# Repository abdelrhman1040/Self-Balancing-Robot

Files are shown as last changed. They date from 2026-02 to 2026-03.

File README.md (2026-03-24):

# Self-Balancing Robot
### Inverted Pendulum Modeling, Embedded Control, and Real-Time PID Tuning Platform

</div>

## Project Overview

This project implements a self-balancing robot based on the classical inverted pendulum problem. The system is inherently unstable and requires continuous feedback control to maintain its upright position.

Distinct from standard implementations, this robot features a **Web-based Dashboard** hosted directly on the ESP32. This allows for **real-time PID tuning** and telemetry visualization over Wi-Fi, eliminating the need to re-upload firmware for parameter adjustments.

### Key Features
* **Mathematical Modeling:** Linearization and transfer function derivation of the system.
* **Control System Design:** Implementation of cascaded PID loops for stability and drift control.
* **Embedded Firmware:** High-frequency control loop execution on the ESP32 dual-core architecture.
* **Web Interface:** Real-time tuning and data plotting using WebSockets.
* **Hardware Implementation:** Custom PCB design and 3D printed mechanical chassis.

### Applications
* Autonomous robotics platforms.
* Mobile balancing transport systems.
* Educational control systems laboratories.
* Real-time embedded control experimentation.

---

## Repository Contents

This repository is organized into the following directories:

* **[`/Firmware`](./Firmware)**: Source code (PlatformIO/Arduino) and libraries.
* **[`/PCB`](./PCB)**: EasyEDA Gerber files, schematics, and BOM.
* **[`/Mechanical`](./Mechanical)**: STL files for 3D printing and CAD models.
* **[`/Hardware`](./Hardware)**: Component datasheets, wiring diagrams, and hardware specifications.

---

## Hardware Assembly

### 1. Mechanical Assembly

1.  **Chassis Fabrication:** 3D print the chassis using the STL files provided in the `/Mechanical` directory.
2.  **Motor Mounting:** Mount the NEMA17 stepper motors in the designated chassis slots.
3.  **Drive Train:** Securely attach the wheels to the motor shafts.
4.  **Electronics Mounting:** Fix the PCB in its mounting slots using M3 screws.
5.  **IMU Alignment:** Place the BNO055 IMU sensor at the physical center of the robot.
    * *Note:* Misalignment introduces centrifugal acceleration artifacts into the tilt reading.
6.  **Center of Mass:** Ensure the center of mass is aligned vertically above the wheel axis.

### 2. Electrical Assembly

Connect the components according to the schematic provided in the `/PCB` directory:

* **Microcontroller:** ESP32 Development Board.
* **Actuators:** Two Stepper Motors driven by A4988 or DRV8825 drivers.
* **Sensor:** BNO055 IMU communicating via I2C (SDA, SCL).
* **Power Management:** Buck converter (16V to 5V) for logic supply; direct battery connection for motor drivers.

**Verification Steps:**
* Calibrate motor driver current limits (Vref).
* Verify common ground continuity between logic and power circuits.
* Ensure I2C connections are secure and shielded.

---

## Firmware Configuration and Upload

To configure and upload the firmware:

1.  Open the project in **PlatformIO** or **Arduino IDE**.
2.  Navigate to the main configuration file (e.g., `config.h` or `main.cpp`).
3.  Update the Wi-Fi credentials:

    ```cpp
    const char* ssid = "your_wifi_name";
    const char* password = "your_wifi_password";
    ```

4.  Upload the firmware to the ESP32.
5.  Open the Serial Monitor (Baud Rate: 115200).
6.  Upon successful connection, the ESP32 will output its assigned IP address.
7.  Enter this IP address in a web browser to access the control dashboard.

---

## Mathematical Modeling

The robot is modeled as an inverted pendulum mounted on a wheeled cart.

```math
(M + m)\ddot{x} + mL \cos\theta \ddot{\theta}
- mL\dot{\theta}^2 \sin\theta = F(x)
```
### 2. Pendulum Rotation

```math
mL \cos\theta \ddot{x}
+ (I + mL^2)\ddot{\theta}
- mgL\sin\theta = d(\theta)
```

These equations contain nonlinear terms:
$\sin\theta$, $\cos\theta$, $\dot{\theta}^2$

For small angles:

$$
\sin\theta \approx \theta
$$

$$
\cos\theta \approx 1
$$

The simplified equation becomes:

$$
(I + mL^2)\ddot{\theta} - mgL\theta = d(\theta)
$$

### Transfer Function

$$
\frac{\Theta(s)}{D(s)} = \frac{1}{s^2 - a}
$$

Where

$$
a = \frac{mgL}{I + mL^2}
$$

Poles:

$$
s = \pm \sqrt{a}
$$

### Embedded Control Architecture

The firmware utilizes a **Cascaded Control Architecture**:

1.  **Balance Loop (Inner Loop):**
    * Operates at high frequency (~200Hz).
    * Calculates motor speed based on tilt angle.
    * Includes anti-windup and deadband compensation.

    ```cpp
    float term_bP = Kp * balanceError;
    float term_bI = Ki * sumBalanceError;
    float term_bD = Kd * (balanceError - lastBalanceError);
    ```

2.  **Speed/Drift Loop (Outer Loop):**
    * Operates at a lower frequency.
    * Adjusts the target angle setpoint to prevent linear drift across the floor.

    ```cpp
    float term_sP = speedOutput * Kp_s;
    float term_sI = sumSpeedError * Ki_s;
    float driftCorrection = term_sP + term_sI;
    ```

---

## Web Dashboard Interface

The ESP32 hosts an asynchronous web server providing a control interface with the following functionalities:

* **Parameter Tuning:** Sliders for adjusting $K_p$, $K_i$, and $K_d$ values for both balance and speed loops instantly.
* **Telemetry:** Live plotting of tilt angle, motor speed, and PID output using Chart.js.
* **Control:** Remote start/stop functionality.
* **Data Persistence:** Capability to save and load tuning profiles from non-volatile memory (EEPROM).



<div align="center">

<a href="https://www.youtube.com/shorts/-zBhrWm9mPE" target="_blank">
   Watch Video
</a>

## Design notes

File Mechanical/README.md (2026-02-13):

# Mechanical Specifications

* **Material:** PLA+ 

| Component | Infill Percentage | Infill Pattern |
| :--- | :---: | :---: |
| **Wheels** | **50%** | Gyroid / Grid | 
| **Main Body** | **30%** | Tri-Hexagonal | 



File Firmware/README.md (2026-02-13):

# Firmware Documentation

## Overview
The firmware is built on the Arduino Framework specifically for the ESP32 Dual-Core architecture. It is designed to decouple critical real-time control loops from non-deterministic Wi-Fi and Web Server tasks. This separation ensures that heavy network traffic or web dashboard updates do not interrupt the PID loop, maintaining consistent stability for the robot.

---

## System Architecture

The firmware utilizes FreeRTOS to distribute tasks across the two cores of the ESP32:

### 1. Core 1: Real-Time Control Task (High Priority)
This core is dedicated to the physics and stability of the robot.
* Frequency: ~100Hz (10ms loop time).
* Responsibilities:
    * Sensor Fusion: Reads absolute orientation data from the BNO055 IMU via I2C.
    * PID Calculation: Computes the Cascaded PID output (Balance Inner Loop + Speed Outer Loop).
    * Motor Drive: Generates step pulses using the AccelStepper library with acceleration limiting.
    * Safety Checks: Monitors tilt angle (automatic cutoff at >45 degrees) and sensor connectivity.

### 2. Core 0: Communication Task (Low Priority)
This core handles user interaction and network management.
* Responsibilities:
    * Wi-Fi Management: Handles connection stability and re-connection logic.
    * Web Server: Serves the HTML/JavaScript Dashboard to the browser.
    * API Handling: Processes AJAX requests for real-time tuning and telemetry data.
    * NVS Storage: Manages reading/writing tuning profiles to Flash memory via the Preferences library.

---

## Dependencies and Libraries

The following libraries are required to compile the project:

| Library | Purpose |
| :--- | :--- |
| Adafruit BNO055 | Driver for the IMU sensor to read Euler angles. |
| Adafruit Unified Sensor | Base dependency for Adafruit sensor libraries. |
| AccelStepper | Multi-stepper control with acceleration support. |
| Preferences | Non-Volatile Storage (NVS) management on ESP32. |
| WebServer | Standard library for handling HTTP requests. |

---

## Pin Definitions and Hardware Compatibility

The firmware defaults to the configuration for PCB Version 1 (V1).

### Current Pinout (V1 Default)
```cpp
#define STEP_PIN_1   14   // Left Motor Step
#define DIR_PIN_1    12   // Left Motor Dir
#define STEP_PIN_2   26   // Right Motor Step
#define DIR_PIN_2    27   // Right Motor Dir
#define SDA_PIN      21   // BNO055 SDA
#define SCL_PIN      22   // BNO055 SCL
```

---

## Important for PCB V2 Users
The PCB Version 2 design avoids using GPIO 2 to prevent boot-strapping issues. If you are deploying this firmware on a V2 board, you must update the pin definitions in the source code to match the V2 schematic before uploading. Failure to do so may result in boot loops or unresponsive motors.

---

## Troubleshooting and System Stability

### Brownout Detector Issue (PCB V1)
In the initial PCB design (V1), the power path is shared between high-current stepper drivers and the ESP32 logic without complete electrical isolation.

**The Problem:**
Rapid motor acceleration causes significant current spikes, leading to a momentary voltage drop on the 3.3V rail. The ESP32's internal Brownout Detector interprets this as a power failure and resets the chip, causing a continuous boot loop during operation.

**The Software Solution:**
If your robot resets whenever it tries to balance or move (especially on PCB V1), the code includes a fix to disable the Brownout Detector at the start of the setup function:

```cpp
#include "soc/soc.h"
#include "soc/rtc_cntl_reg.h"

void setup() {
    // Disabling Brownout Detector to allow operation during current spikes
    WRITE_PERI_REG(RTC_CNTL_BROWN_OUT_REG, 0);
    
    // ... remaining setup logic
}
```

> **Note:** While this software fix allows the robot to run, ensure your 3S LiPo battery is adequately charged to maintain voltage stability.

---

## API Endpoints (Web Interface)
The Web Dashboard interacts with the ESP32 through HTTP GET requests.

| Endpoint | Description |
| :--- | :--- |
| **`GET /data`** | Returns a JSON object with live telemetry (Angle, Speed, PID components). |
| **`GET /set?k=[KEY]&v=[VALUE]`** | Updates PID constants instantly.<br>**Keys:** `bp` (Balance P), `bi` (Balance I), `bd` (Balance D), `sp` (Setpoint). |
| **`GET /save?p=[SLOT]`** | Saves current tuning to Slot 1, 2, or 3 in Flash memory. |
| **`GET /move?d=[DIRECTION]`** | Sends movement commands.<br>**Values:** `F` (Forward), `B` (Backward), `L` (Left), `R` (Right). |

WhatsApp Image 2026-02-13 at 10 07 07 PM



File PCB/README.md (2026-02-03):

## PCB Versions

### Version 1 (V1) - Prototype
This version represents the initial design of the board, characterized by the following specifications and limitations:

* **Microcontroller:** The board only supports the 38-pin ESP32 module.
* **Power:** The power path is shared between the step-down converter and the ESP32 without isolation, preventing USB connection while running on an external battery.
* **Drivers Logic:** Operates at a fixed 3.3V logic voltage (may not be compatible with some clone A4988 drivers that require 5V, unless tracks are manually modified).
* **Control:** Microstepping and Enable settings are hardwired (manually set) and cannot be controlled via code.
* **Installation Notes:**
    * Installing headers requires connecting only the used pins to avoid restart loop issues.
    * The sensor port footprint is reversed by 180 degrees.

---

### Version 2 (V2) - Improved Version
This version was developed to include comprehensive improvements in power management, compatibility, and pin selection:

* **Controller Support:** The board supports mounting ESP32 modules of two different sizes: **30-pin** and **38-pin**.
* **Power Management:**
    * **Isolation Switch:** Allows disconnecting the step-down output from the ESP32, enabling safe chip programming via USB without disconnecting the external power source.
    * **Logic Voltage Selection:** A switch to select the drivers' logic voltage between **3.3V** and **5V** to ensure compatibility with all driver types.
* **Software Control:** Control pins (MS1, MS2, MS3) and the Enable pin are connected to the microcontroller (GPIO) to allow full software control.
* **Pin Selection Optimization:** Avoided using **GPIO 2** for driver control to prevent booting issues occasionally caused by this pin.
* **Extras:**
    * **Voltage Sensor:** Integrated circuit to read input voltage (up to **17V** max).
    * **Track Correction:** The sensor ports' orientation has been corrected to the standard position.

---

### ⚠️ Important Notes
* This design (V2) is still experimental and has not been practically tested yet (Untested).

* Due to the change in the Pinout for this version (specifically avoiding GPIO 2), the Pin Definitions in the software code must be updated to match the new connections before operation.

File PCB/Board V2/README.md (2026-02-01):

# PCB V2




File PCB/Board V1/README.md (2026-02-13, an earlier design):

# PCB V1




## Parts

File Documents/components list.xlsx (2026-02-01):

Name | quantity | connection protocol | datasheet
ESP32 DIP-38 | 1 | ___ | https://documentation.espressif.com/esp32_datasheet_en.pdf
42BYGH37 | 2 | GPIO | https://joy-it.net/files/files/Produkte/NEMA17-06/NEMA17-06_Datasheet.pdf
MAX7219 8X8 | 2 | SPI | MAX7219/MAX7221 - Serially Interfaced, 8-Digit LED Display Drivers (https://www.analog.com/media/en/technical-documentation/data-sheets/max7219-max7221.PDF)
GY-BNO055 | 1 | I2C | https://cdn-shop.adafruit.com/datasheets/BST_BNO055_DS000_12.pdf
PCB | 1 | ___ | ___
18650 Battery Holder – 2 Cells | 2 | ___ | ___
8650 Li-ion Battery Samsung | 4 | ___ | ___
LM2596 DC-DC Buck Converter Step-Down | 1 | ___ | https://www.ti.com/lit/ds/symlink/lm2596.pdf
A4988 Stepper Motor Driver | 2 | GPIO | https://www.pololu.com/file/0j450/a4988_dmos_microstepping_driver_with_translator.pdf
Electrolytic Capacitor 100uF – 50v | 2 | ___ | ___
Pin Header Female | 2 | ___ | ___
Pin Header Male | 2 | ___ | ___

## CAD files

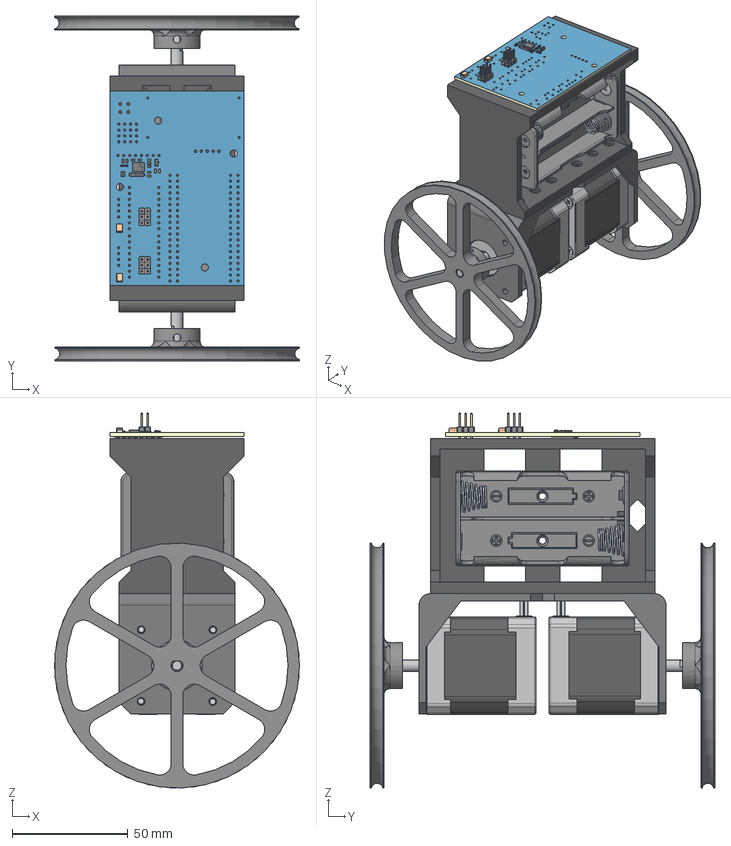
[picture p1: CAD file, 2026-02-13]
Mechanical/Self Balancing Robot.step
106.0 x 149.0 x 162.2 mm
NEMA_17_Bracket x 2
17HM19-2004S x 2
Wheel v2 x 2
spring x 4
2_rivets_1 x 2
2_rivets_2 x 2
positif x 4
Board~hV0o
HDR-TH_3P-P2.54-V-M-1~HDR-M-2.54_1x3~hV0o x 4
ELECTROLYTIC_CAPACITOR_5X11~CAP-SMD_L3.5-W2.8-FD~hV0o x 2
BNO055~GY-BNO055~hV0o
BNO055~GY-BNO055~hV0o_1
BNO055~GY-BNO055~hV0o_2
BNO055~GY-BNO055~hV0o_3
BNO055~GY-BNO055~hV0o_4
BNO055~GY-BNO055~hV0o_5
BNO055~GY-BNO055~hV0o_6
BNO055~GY-BNO055~hV0o_7
BNO055~GY-BNO055~hV0o_8
BNO055~GY-BNO055~hV0o_9
BNO055~GY-BNO055~hV0o_10
BNO055~GY-BNO055~hV0o_11
BNO055~GY-BNO055~hV0o_12
BNO055~GY-BNO055~hV0o_13
BNO055~GY-BNO055~hV0o_14
BNO055~GY-BNO055~hV0o_15
BNO055~GY-BNO055~hV0o_16
BNO055~GY-BNO055~hV0o_17
BNO055~GY-BNO055~hV0o_18
BNO055~GY-BNO055~hV0o_19

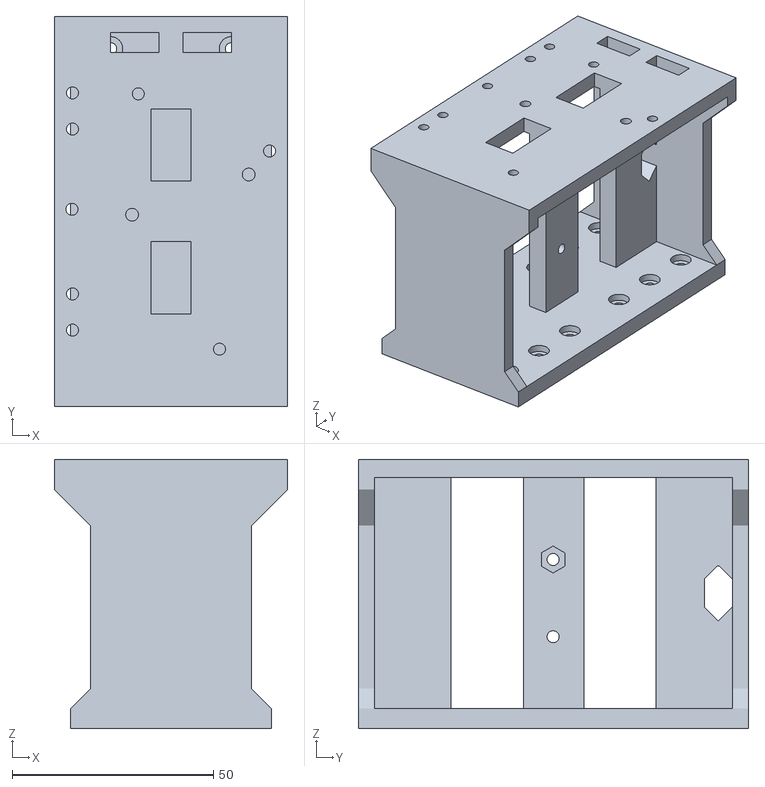
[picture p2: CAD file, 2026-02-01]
Mechanical/body.stl
58.0 x 97.0 x 67.0

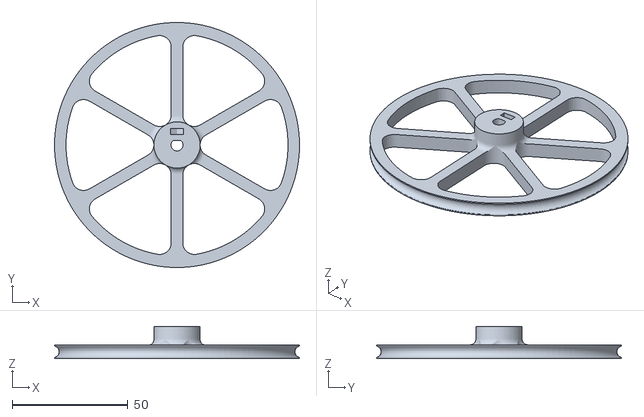
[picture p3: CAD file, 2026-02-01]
Mechanical/Wheel 6.stl
106.0 x 106.0 x 14.0

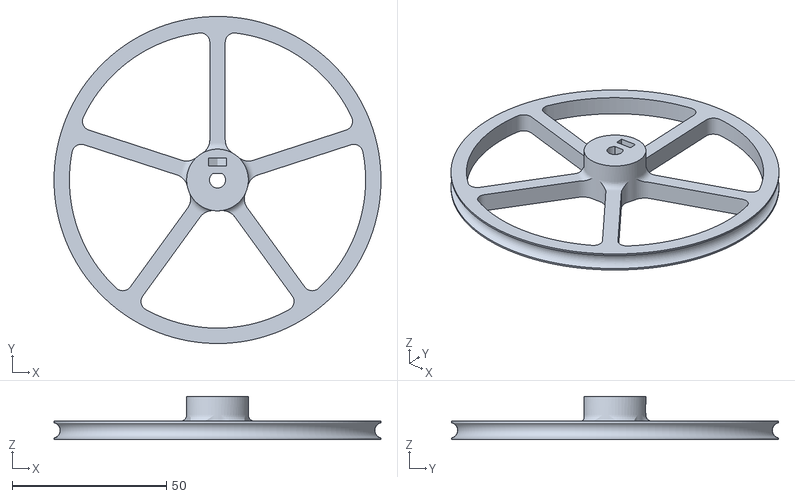
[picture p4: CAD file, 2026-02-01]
Mechanical/Wheel 5.stl
106.0 x 106.0 x 14.0

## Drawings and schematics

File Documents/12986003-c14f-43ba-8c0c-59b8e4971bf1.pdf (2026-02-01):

ESP32 | GPIO

# A4988 Stepper 1

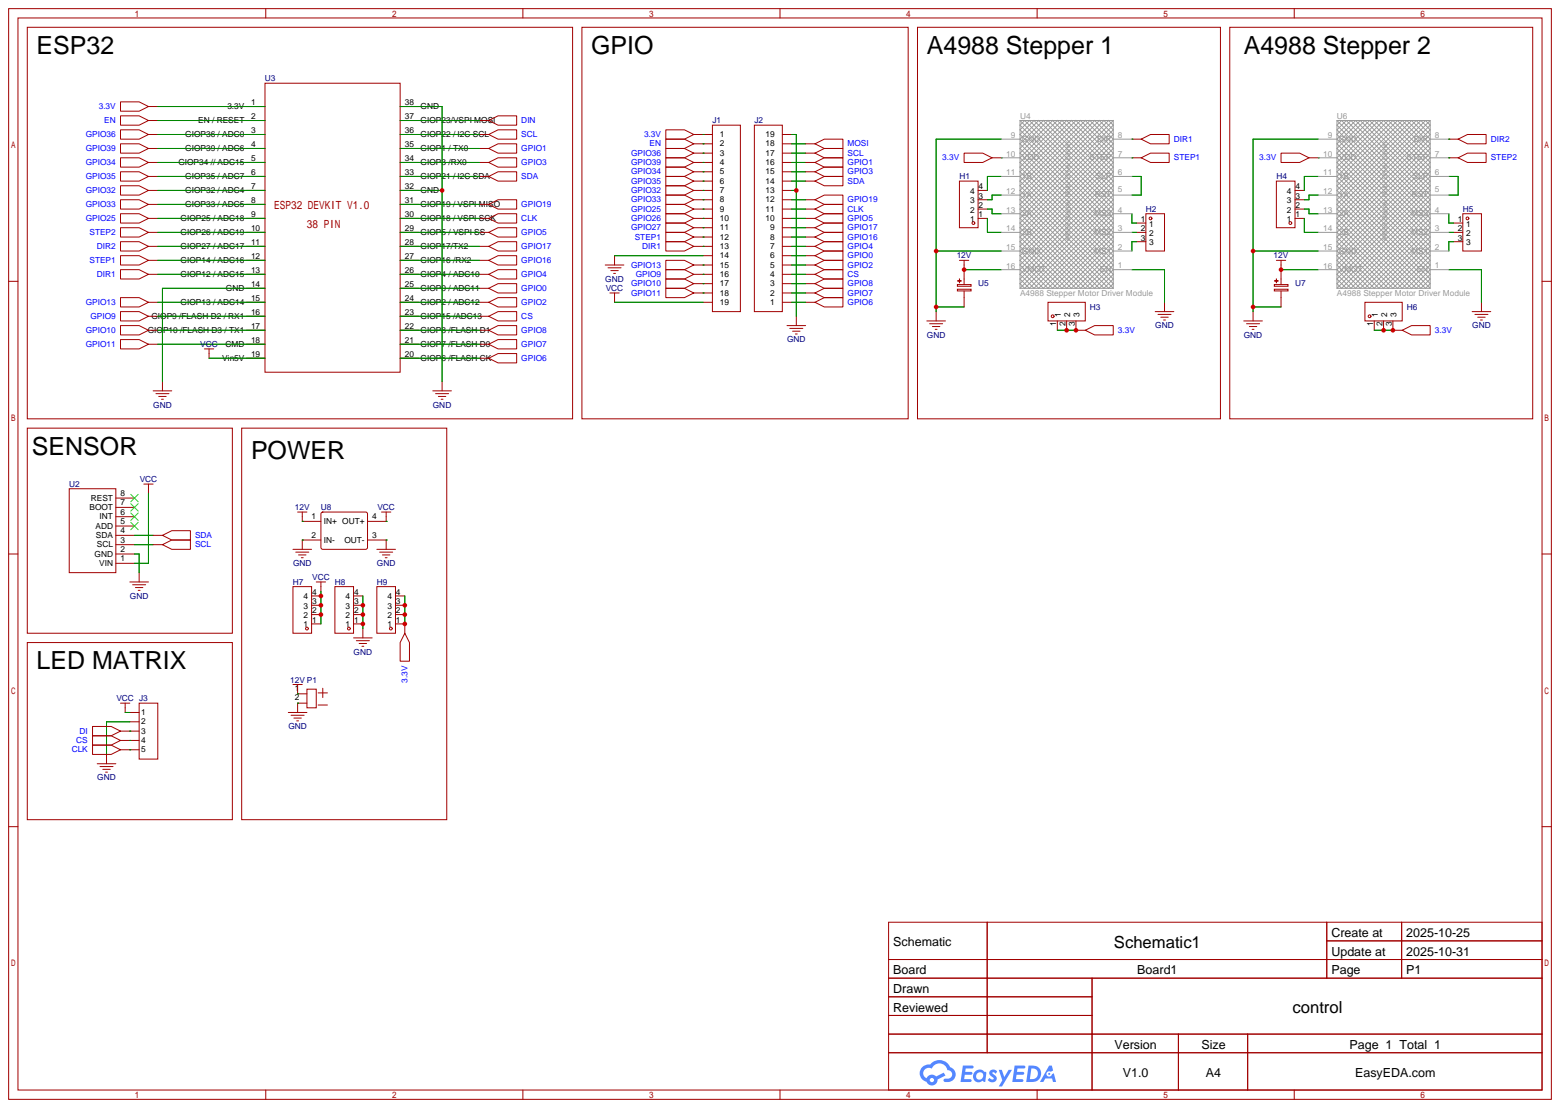
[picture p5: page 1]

A4988 Stepper Motor Driver Carrier

A4988 Stepper Motor Driver Module

Schematic | Schematic1 | Create at | 2025-10-25

Update at | 2025-10-31

Board | Board1 | Page | P1
Drawn | | control
Reviewed

Version | Size | Page 1 Total 1
V1.0 | A4 | EasyEDA.com

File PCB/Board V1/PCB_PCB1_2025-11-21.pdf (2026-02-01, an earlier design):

P1
IN+

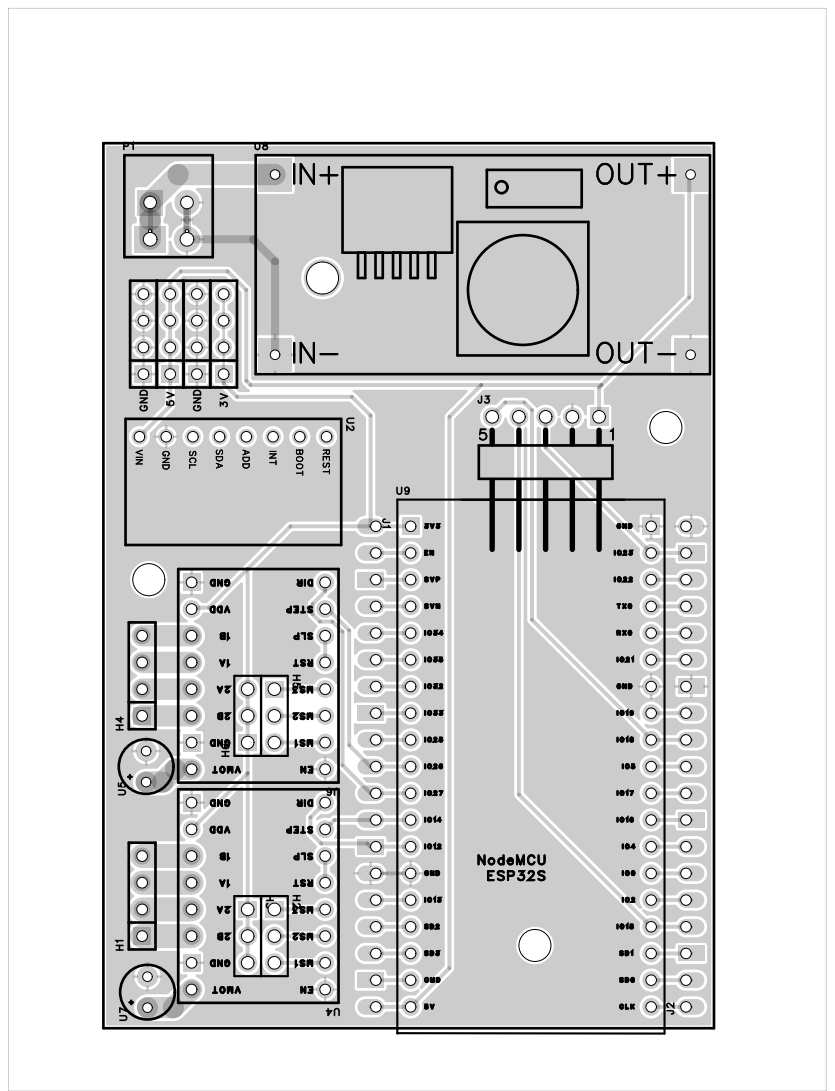
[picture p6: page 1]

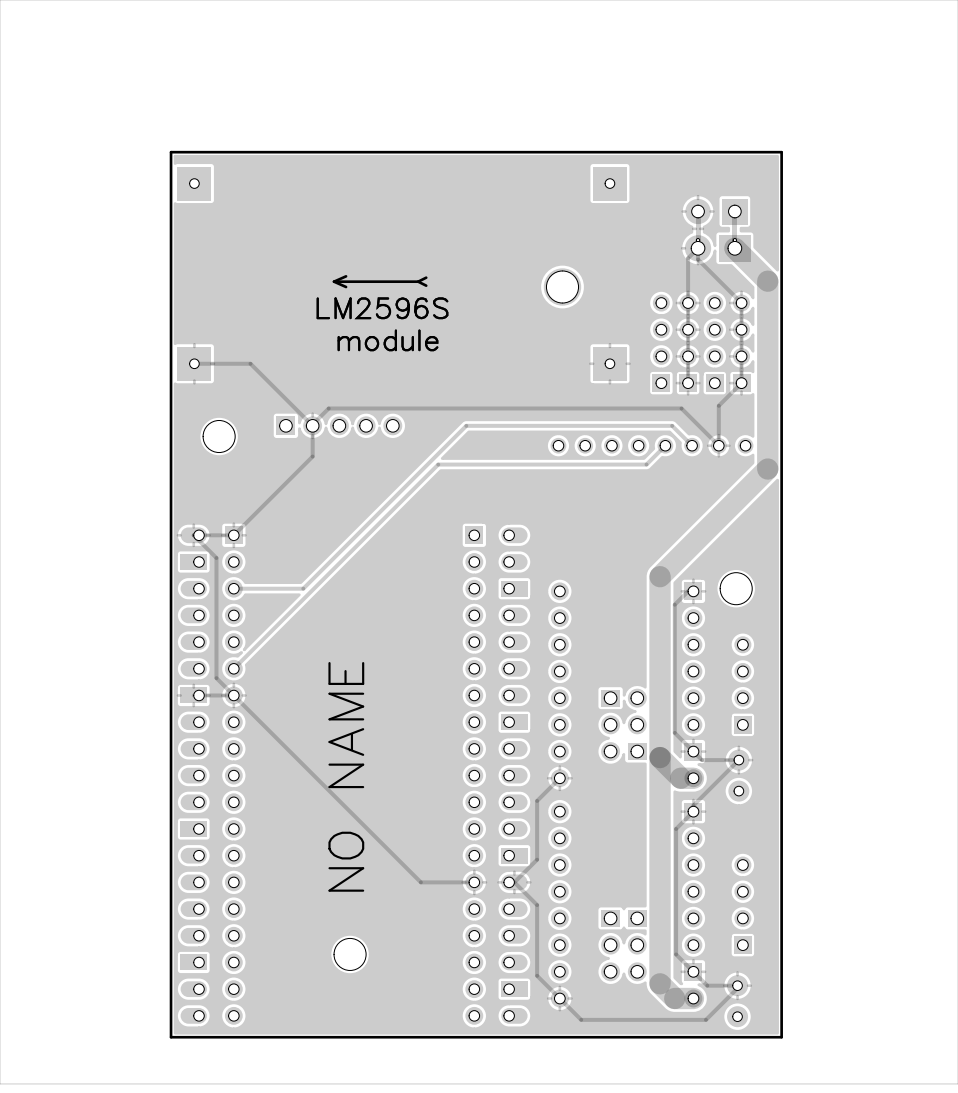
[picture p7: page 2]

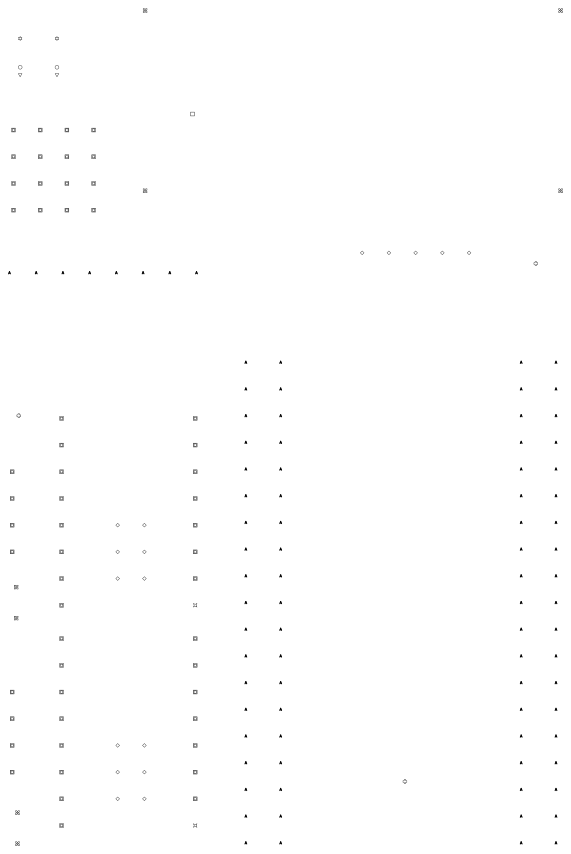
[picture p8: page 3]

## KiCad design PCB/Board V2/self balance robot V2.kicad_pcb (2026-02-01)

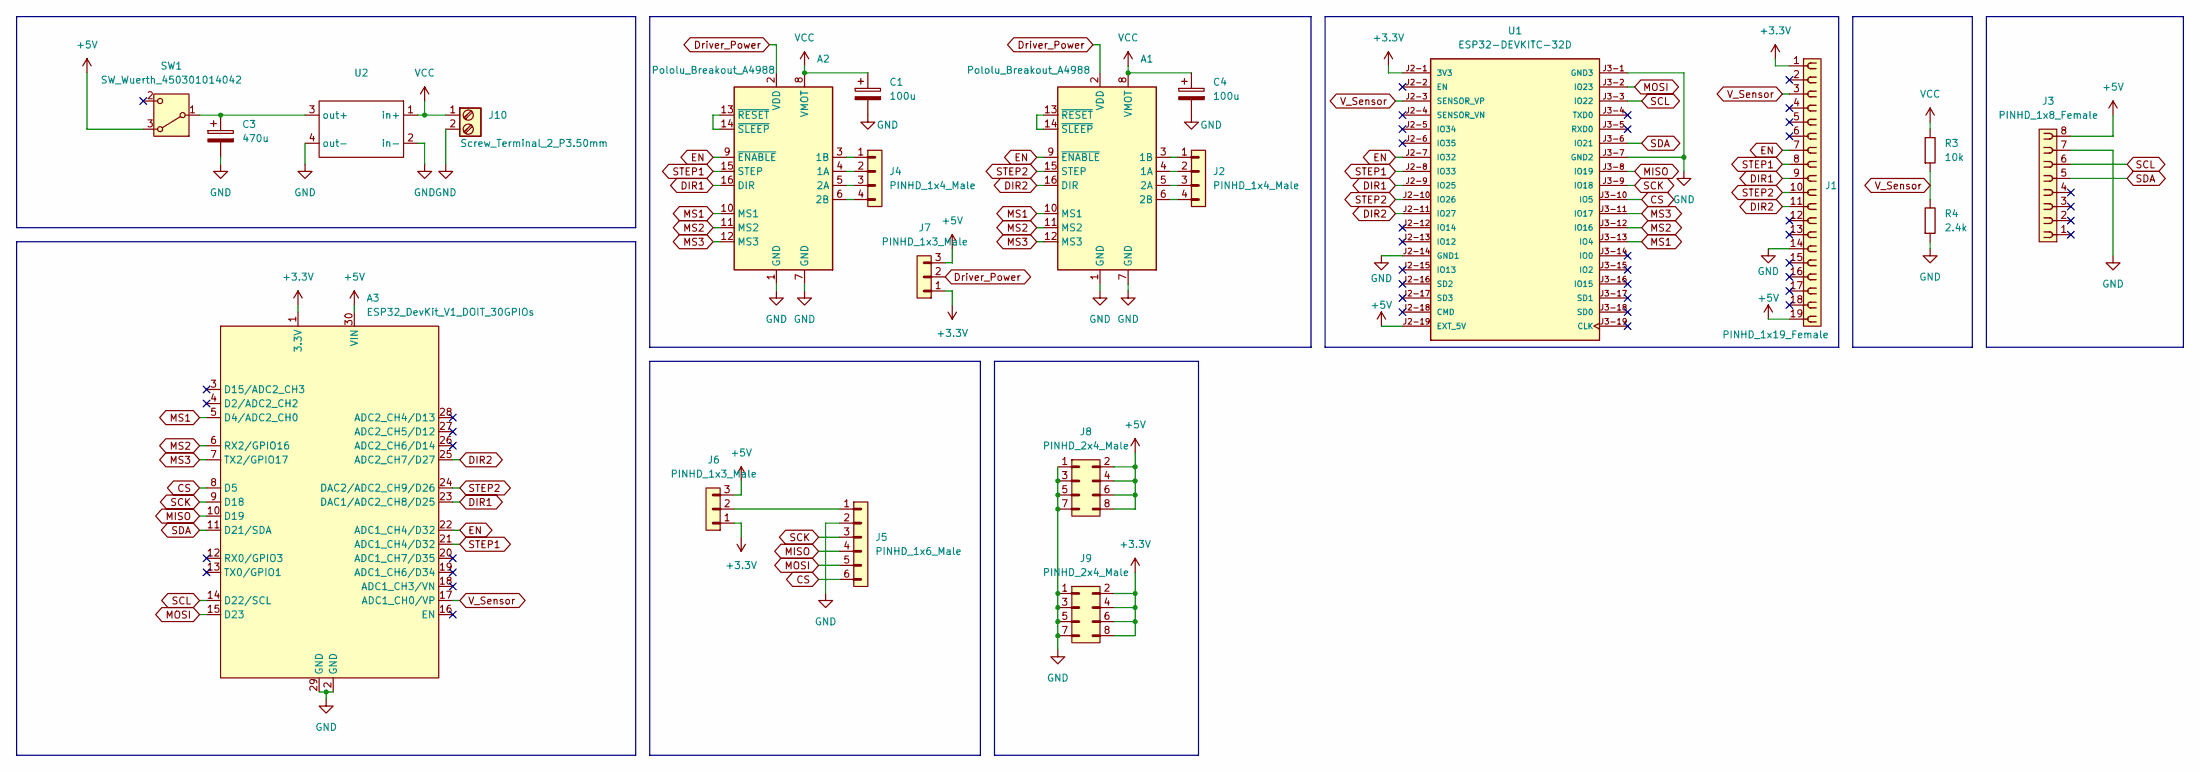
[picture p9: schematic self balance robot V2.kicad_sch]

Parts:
A1, A2: Pololu_Breakout_A4988; Pololu_Breakout-16_15.2x20.3mm
A3: ESP32_DevKit_V1_DOIT_30GPIOs; DOIT_ESP32_DEVKIT_30Pins
C1, C4: 100u; CP_Radial_D5.0mm_P2.50mm
C3: 470u; CP_Radial_D5.0mm_P2.50mm
J1: PINHD_1x19_Female; PinSocket_1x19_P2.54mm_Vertical
J2, J4: PINHD_1x4_Male; PinHeader_1x04_P2.54mm_Vertical
J3: PINHD_1x8_Female; PinSocket_1x08_P2.54mm_Vertical
J5: PINHD_1x6_Male; PinHeader_1x06_P2.54mm_Vertical
J6, J7: PINHD_1x3_Male; PinHeader_1x03_P2.54mm_Vertical
J8, J9: PINHD_2x4_Male; PinHeader_2x04_P2.54mm_Vertical
J10: Screw_Terminal_2_P3.50mm; TerminalBlock_Phoenix_PT-1,5-2-3.5-H_1x02_P3.50mm_Horizontal
R3: 10k; R_Axial_DIN0207_L6.3mm_D2.5mm_P10.16mm_Horizontal
R4: 2.4k; R_Axial_DIN0207_L6.3mm_D2.5mm_P10.16mm_Horizontal
SW1: SW_Wuerth_450301014042; SW_Slide-03_Wuerth-WS-SLTV_10x2.5x6.4_P2.54mm
U1: ESP32-DEVKITC-32D; MODULE_ESP32-DEVKITC-32D; PARTREV V4
U2: mini360

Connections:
+3.3V: A3.1 (3.3V), J1.1, J6.1, J7.1, J9.2, J9.4, J9.6, J9.8, U1.J2-1 (3V3)
+5V: A3.30 (VIN), J1.19, J3.8, J6.3, J7.3, J8.2, J8.4, J8.6, J8.8, SW1.3 (A), U1.J2-19 (EXT_5V)
CS: A3.8 (D5), J5.6, U1.J3-10 (IO5)
DIR1: A2.16 (DIR), A3.23 (DAC1/ADC2_CH8/D25), J1.9, U1.J2-9 (IO25)
DIR2: A1.16 (DIR), A3.25 (ADC2_CH7/D27), J1.11, U1.J2-11 (IO27)
Driver_Power: A1.2 (VDD), A2.2 (VDD), J7.2
EN: A1.9 (~ENABLE), A2.9 (~ENABLE), A3.22 (ADC1_CH4/D32), J1.7, U1.J2-7 (IO32)
GND: A1.1 (GND), A1.7 (GND), A2.1 (GND), A2.7 (GND), A3.2 (GND), A3.29 (GND), C1.2, C3.2, C4.2, J1.14, J3.7, J5.2, J8.1, J8.3, J8.5, J8.7, J9.1, J9.3, J9.5, J9.7, J10.2, R4.1, U1.J2-14 (GND1), U1.J3-1 (GND3), U1.J3-7 (GND2), U2.2 (in-), U2.4 (out-)
MISO: A3.10 (D19), J5.4, U1.J3-8 (IO19)
MOSI: A3.15 (D23), J5.5, U1.J3-2 (IO23)
MS1: A1.10 (MS1), A2.10 (MS1), A3.5 (D4/ADC2_CH0), U1.J3-13 (IO4)
MS2: A1.11 (MS2), A2.11 (MS2), A3.6 (RX2/GPIO16), U1.J3-12 (IO16)
MS3: A1.12 (MS3), A2.12 (MS3), A3.7 (TX2/GPIO17), U1.J3-11 (IO17)
unnamed: A1.4 (1A), J2.2
unnamed: A1.3 (1B), J2.1
unnamed: A1.5 (2A), J2.3
unnamed: A1.6 (2B), J2.4
unnamed: A1.13 (~RESET), A1.14 (~SLEEP)
unnamed: A2.4 (1A), J4.2
unnamed: A2.3 (1B), J4.1
unnamed: A2.5 (2A), J4.3
unnamed: A2.6 (2B), J4.4
unnamed: A2.13 (~RESET), A2.14 (~SLEEP)
unnamed: J5.1, J6.2
unnamed: C3.1, SW1.1 (B), U2.3 (out+)
SCK: A3.9 (D18), J5.3, U1.J3-9 (IO18)
SCL: A3.14 (D22/SCL), J3.6, U1.J3-3 (IO22)
SDA: A3.11 (D21/SDA), J3.5, U1.J3-6 (IO21)
STEP1: A2.15 (STEP), A3.21 (ADC1_CH4/D32), J1.8, U1.J2-8 (IO33)
STEP2: A1.15 (STEP), A3.24 (DAC2/ADC2_CH9/D26), J1.10, U1.J2-10 (IO26)
VCC: A1.8 (VMOT), A2.8 (VMOT), C1.1, C4.1, J10.1, R3.2, U2.1 (in+)
V_Sensor: A3.17 (ADC1_CH0/VP), J1.3, R3.1, R4.2, U1.J2-3 (SENSOR_VP)

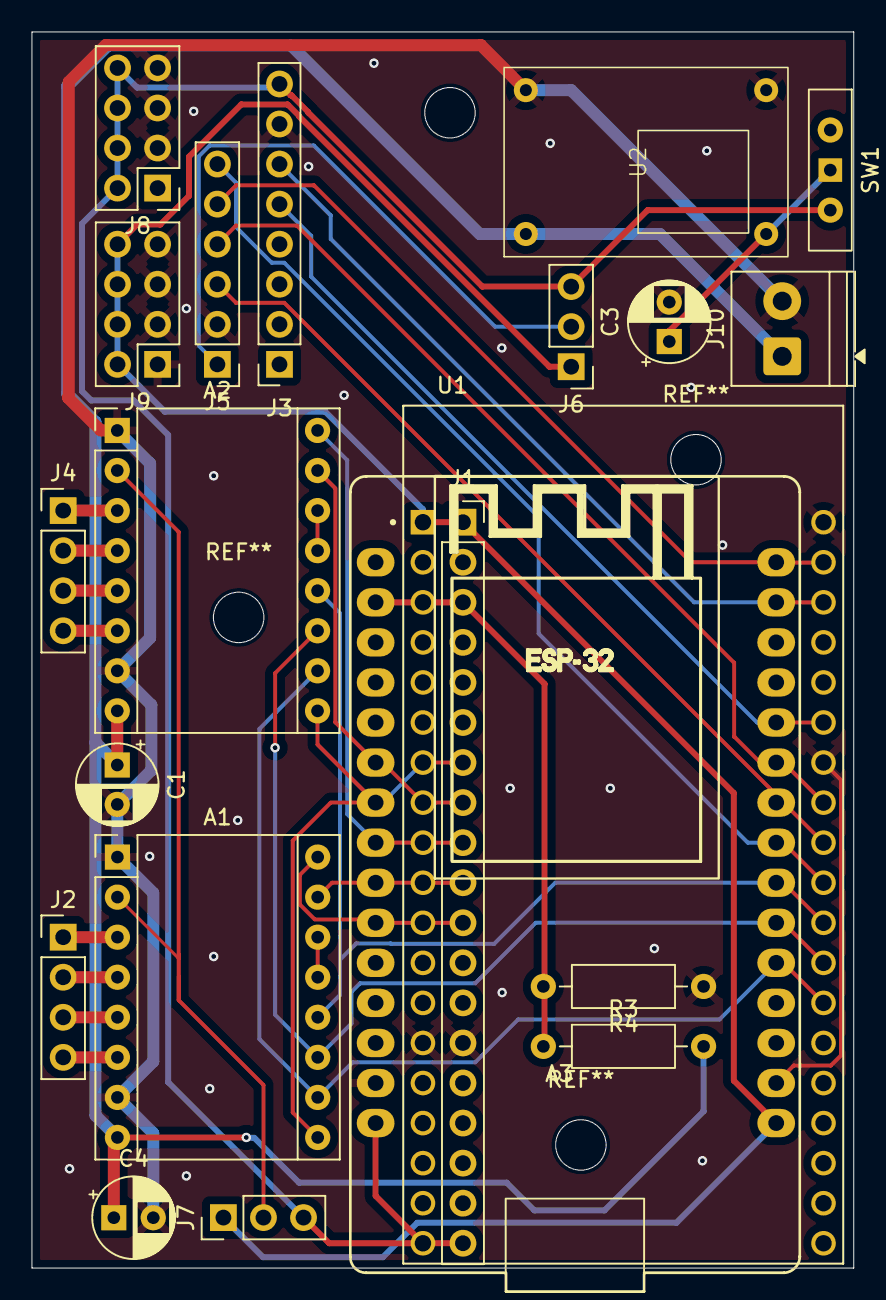
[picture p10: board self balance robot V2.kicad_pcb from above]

Board: 2 copper layers, 52.1 x 78.4 mm, 21 parts (0 on the bottom side), 32 nets.

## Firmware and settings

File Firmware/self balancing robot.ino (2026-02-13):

#include <Wire.h>
#include <Adafruit_Sensor.h>
#include <Adafruit_BNO055.h>
#include <AccelStepper.h>
#include <Preferences.h>
#include <WiFi.h>
#include <WebServer.h>
#include "soc/soc.h"
#include "soc/rtc_cntl_reg.h"

// --- Network Settings ---
const char* ssid = "your_wifi_name";
const char* password = "your_wifi_password";

// --- System Objects ---
Preferences preferences;
WebServer server(80);
Adafruit_BNO055 bno = Adafruit_BNO055(55, 0x29); 

// --- Pin Definitions ---
#define STEP_PIN_1   14   
#define DIR_PIN_1    12    
#define STEP_PIN_2   26   
#define DIR_PIN_2    27   

AccelStepper stepper1(AccelStepper::DRIVER, STEP_PIN_1, DIR_PIN_1);
AccelStepper stepper2(AccelStepper::DRIVER, STEP_PIN_2, DIR_PIN_2);

// --- PID Control Variables ---
volatile float Kp = 383, Ki = 5.3, Kd = 198.5;
volatile float setPoint = -1.4;
float deadband = 0.5;

// --- Drift Control ---
volatile float Kp_s = 0.0008; 
volatile float Ki_s = 0.0001; 

// --- Profile Management ---
int activeProfile = 1;

// --- Movement Variables ---
volatile float moveTilt = 0;   
volatile float turnSpeed = 0;  

// --- Variables ---
volatile float displayAngle = 0;
float speedOutput = 0, sumSpeedError = 0;
float lastBalanceError = 0, sumBalanceError = 0;
float desiredAngle = 0;

// --- DEBUG / GRAPH VARIABLES ---
volatile float dbg_bP = 0, dbg_bI = 0, dbg_bD = 0;
volatile float dbg_sP = 0, dbg_sI = 0;

const float FALL_LIMIT = 45.0; 
const float MAX_HW_SPEED = 12000; 
const float MAX_TILT = 5.0; 
bool sensorConnected = false;

TaskHandle_t Task1; 

// --- Web Dashboard ---
const char index_html[] PROGMEM = R"rawliteral(
<!DOCTYPE HTML><html>
<head>
   <meta name="viewport" content="width=device-width, initial-scale=1">
   <title>self balancing robot </title>
   <style>
      body { font-family: 'Segoe UI', sans-serif; background: #000; color: #eee; margin:0; padding:5px; text-align:center; }
      h2 { color: #f39c12; margin: 5px 0; font-size: 18px; }
      
      .container { display: flex; flex-wrap: wrap; justify-content: center; gap: 10px; }
      .card { background: #1e1e1e; padding: 10px; border-radius: 8px; box-shadow: 0 4px 10px rgba(0,0,0,0.5); width: 100%; max-width: 450px; }
      
      .live-vals { display: flex; justify-content: space-around; margin-bottom: 5px; }
      .live-num { font-size: 20px; font-weight: bold; color: #00bcd4; }
      .live-lbl { font-size: 10px; color: #aaa; }
      .lat-num { font-size: 18px; font-weight: bold; color: #e91e63; }

      /* ROBOT VISUALIZER STYLING */
      .vis-container { position: relative; width: 100%; height: 250px; background: #000; border-radius: 10px; border: 1px solid #333; margin-bottom: 10px; overflow: hidden; }
      canvas#cvsRobot { width: 100%; height: 100%; }

      /* Profile Styling */
      .prof-section { background: #222; padding: 10px; border-radius: 5px; margin-bottom: 5px; border: 1px solid #444; }
      .prof-row { display: flex; gap: 5px; margin-bottom: 5px; justify-content: center; }
      .p-btn { flex: 1; padding: 8px; background: #333; border: 1px solid #555; color: #fff; cursor: pointer; border-radius: 4px; font-size: 14px; }
      .p-active { background: #00bcd4; color: #000; font-weight: bold; border-color: #eee; }
      
      .action-btn { width: 48%; padding: 10px; font-weight: bold; cursor: pointer; border: none; border-radius: 5px; color: white; }
      .btn-save { background: #4CAF50; } 
      .btn-load { background: #FF9800; } 
      .btn-save:active, .btn-load:active { transform: scale(0.98); opacity: 0.8; }

      .graph-card { background: #000; border: 1px solid #333; border-radius: 8px; padding: 5px; width: 100%; max-width: 600px; }
      canvas#cvsMaster { width: 100%; height: 300px; display: block; }
      
      .legend { font-size: 11px; margin-top: 5px; display: flex; flex-wrap: wrap; justify-content: center; gap: 8px; }
      .legend label { cursor: pointer; display: flex; align-items: center; gap: 3px; user-select: none; }
      input[type=checkbox] { accent-color: #555; width: 15px; height: 15px; cursor: pointer; }

      input[type=range] { width: 100%; cursor: pointer; margin: 8px 0; }
      .row { display: flex; justify-content: space-between; font-size: 13px; color: #ccc; }
      .btn { background: #2196F3; border: none; color: white; padding: 5px; width: 50px; height: 50px; font-size: 20px; border-radius: 50%; margin: 3px; cursor: pointer; }
      .btn-stop { background: #f44336; width: 70px; height: 70px; border-radius: 15px; }
   </style>
</head>
<body>

   <h2>ESP32 Robot Visualizer</h2>

   <div class="container">
      <div class="card">
          
          <div class="vis-container">
              <canvas id="cvsRobot"></canvas>
          </div>

          <div class="prof-section">
             <div class="prof-row">
                <button id="p1" class="p-btn p-active" onclick="selProf(1)">P1</button>
                <button id="p2" class="p-btn" onclick="selProf(2)">P2</button>
                <button id="p3" class="p-btn" onclick="selProf(3)">P3</button>
             </div>
             <div class="prof-row">
                <button class="action-btn btn-save" onclick="doSave()">SAVE</button>
                <button class="action-btn btn-load" onclick="doLoad()">LOAD</button>
             </div>
          </div>

          <div class="live-vals">
             <div><span id="txtAng" class="live-num">0.0</span><br><span class="live-lbl">Angle</span></div>
             <div><span id="txtSpd" class="live-num">0.00</span><br><span class="live-lbl">m/s</span></div>
             <div><span id="txtLat" class="lat-num">0 ms</span><br><span class="live-lbl">Ping</span></div>
          </div>
      </div>
   </div>

   <div class="container" style="margin-top: 15px;">
      <div class="card">
         <h3>Balance PID</h3>
         <div class="row"><span>Kp</span><span id="v_kp">%KP%</span></div>
         <input id="i_kp" type="range" min="0" max="1200" step="1" value="%KP%" oninput="snd('bp',this.value,'v_kp')">
         <div class="row"><span>Ki</span><span id="v_ki">%KI%</span></div>
         <input id="i_ki" type="range" min="0" max="50" step="0.1" value="%KI%" oninput="snd('bi',this.value,'v_ki')">
         <div class="row"><span>Kd</span><span id="v_kd">%KD%</span></div>
         <input id="i_kd" type="range" min="0" max="500" step="0.5" value="%KD%" oninput="snd('bd',this.value,'v_kd')">
         <div class="row"><span>SetPoint</span><span id="v_sp">%SP%</span></div>
         <input id="i_sp" type="range" min="-10" max="10" step="0.1" value="%SP%" oninput="snd('sp',this.value,'v_sp')">
      </div>

      <div class="card">
         <h3>Speed PID</h3>
         <div class="row"><span>Kp_s</span><span id="v_kps">%KPS%</span></div>
         <input id="i_kps" type="range" min="0" max="0.01" step="0.00001" value="%KPS%" oninput="snd('sp_p',this.value,'v_kps')">
         <div class="row"><span>Ki_s</span><span id="v_kis">%KIS%</span></div>
         <input id="i_kis" type="range" min="0" max="0.001" step="0.00001" value="%KIS%" oninput="snd('sp_i',this.value,'v_kis')">
      </div>

      <div class="card">
         <div><button class="btn" onmousedown="mv('F')" onmouseup="mv('S')" ontouchstart="mv('F')" ontouchend="mv('S')">&#8593;</button></div>
         <div>
            <button class="btn" onmousedown="mv('L')" onmouseup="mv('S')" ontouchstart="mv('L')" ontouchend="mv('S')">&#8592;</button>
            <button class="btn btn-stop" onclick="mv('S')">STOP</button>
            <button class="btn" onmousedown="mv('R')" onmouseup="mv('S')" ontouchstart="mv('R')" ontouchend="mv('S')">&#8594;</button>
         </div>
         <div><button class="btn" onmousedown="mv('B')" onmouseup="mv('S')" ontouchstart="mv('B')" ontouchend="mv('S')">&#8595;</button></div>
      </div>
   </div>

   <div class="container" style="margin-top: 10px;">
      <div class="graph-card">
         <div style="color:#aaa; border-bottom:1px solid #333; margin-bottom:5px;">History Graph</div>
         <canvas id="cvsMaster"></canvas>
         <div class="legend">
            <label style="color:white;"><input type="checkbox" id="cb_ang" checked>Angle</label>
            <label style="color:cyan;"><input type="checkbox" id="cb_spd" checked>Speed</label>
            <label style="color:#ffcc00;"><input type="checkbox" id="cb_bp">Bal-P</label>
            <label style="color:#ff00ff;"><input type="checkbox" id="cb_bi">Bal-I</label>
            <label style="color:#00ff00;"><input type="checkbox" id="cb_bd">Bal-D</label>
         </div>
      </div>
   </div>

<script>
   function id(n){return document.getElementById(n);}
   function snd(k,v,l){ id(l).innerText=v; fetch("/set?k="+k+"&v="+v).catch(e=>console.log(e)); }
   function mv(d){ fetch("/move?d="+d).catch(e=>console.log(e)); }

   // Global Wheel Position (accumulates rotation)
   var wheelPos = 0;

   // --- Robot Visualizer Logic ---
   function drawRobotVisualizer(angle, speedSteps) {
       var cvs = id('cvsRobot');
       var ctx = cvs.getContext('2d');
       var w = cvs.width = cvs.clientWidth;
       var h = cvs.height = cvs.clientHeight;
       
       // Center Coordinates (Pivot at bottom center)
       var cx = w / 2;
       var cy = h - 40; 

       // --- UPDATE WHEEL POSITION ---
       // speedSteps is steps/sec. 3200 steps = 1 rev (2PI rads).
       // Update interval is approx 100ms (0.1s).
       // Delta Angle = (speed / 3200) * 2PI * 0.1
       // We use 0.000196 rads per step-interval approx.
       var deltaRad = (speedSteps / 3200.0) * 2 * Math.PI * 0.1;
       wheelPos += deltaRad;

       ctx.clearRect(0,0,w,h);

       // 1. Draw Faint Background Arcs
       var rOuter = (h - 60); 
       var rInner = rOuter - 60;

       ctx.beginPath();
       ctx.arc(cx, cy, rOuter, Math.PI, 0); 
       ctx.strokeStyle = "#333"; ctx.lineWidth = 1; ctx.stroke();
       
       ctx.beginPath();
       ctx.arc(cx, cy, rInner, Math.PI, 0); 
       ctx.strokeStyle = "#333"; ctx.lineWidth = 1; ctx.stroke();

       // Vertical Zero Line
       ctx.beginPath();
       ctx.moveTo(cx, cy - rOuter - 10);
       ctx.lineTo(cx, cy);
       ctx.strokeStyle = "#ff9800"; ctx.lineWidth = 2; ctx.stroke();

       // 2. Draw Robot Body (Tilting)
       ctx.save();
       ctx.translate(cx, cy);
       ctx.rotate(angle * Math.PI / 180);

       // Body Outline
       ctx.strokeStyle = "white";
       ctx.lineWidth = 4;
       ctx.lineJoin = "round";
       ctx.strokeRect(-25, -120, 50, 120);

       // 3. Draw Wheel (Spinning)
       // We create a nested rotation for the wheel spokes
       ctx.save(); 
       // Translate is already at (0,0) relative to body pivot, which is correct for the wheel hub
       ctx.rotate(wheelPos); // Rotate spokes by accumulated speed

       // Wheel Circle (Static relative to hub, but we draw it here)
       ctx.fillStyle = "black"; 
       ctx.beginPath();
       ctx.arc(0, 0, 28, 0, Math.PI*2);
       ctx.fill(); 
       
       ctx.strokeStyle = "white";
       ctx.lineWidth = 3;
       ctx.stroke();

       // Spokes (5 lines, spinning)
       ctx.lineWidth = 2;
       ctx.beginPath();
       for(let i=0; i<5; i++) {
           let rad = (i * 2 * Math.PI / 5) - (Math.PI/2); 
           ctx.moveTo(0,0);
           ctx.lineTo(28 * Math.cos(rad), 28 * Math.sin(rad));
       }
       ctx.stroke();

       ctx.restore(); // Restore from Wheel Rotation

       // Center Dot (Static on hub)
       ctx.fillStyle = "white";
       ctx.beginPath();
       ctx.arc(0, 0, 4, 0, Math.PI*2);
       ctx.fill();

       ctx.restore(); // Restore from Body Rotation

       // 4. Floor Line
       ctx.strokeStyle = "white";
       ctx.lineWidth = 2;
       ctx.beginPath();
       ctx.moveTo(0, cy + 30); 
       ctx.lineTo(w, cy + 30);
       ctx.stroke();
       
       // 5. Angle Text (Color Logic)
       if(Math.abs(angle) <= 2.0) {
           ctx.fillStyle = "#00ff00"; 
       } else {
           ctx.fillStyle = "#ff0000"; 
       }
       
       ctx.font = "bold 24px Segoe UI";
       ctx.textAlign = "center";
       ctx.fillText(angle.toFixed(1) + "°", cx, h - 5);
   }

   // --- Profile Logic ---
   var currentSlot = 1;
   function selProf(p) {
       currentSlot = p;
       for(let i=1; i<=3; i++) id('p'+i).className = "p-btn";
       id('p'+p).className = "p-btn p-active";
   }
   function doSave() {
       if(confirm("Save to P" + currentSlot + "?")) fetch("/save?p=" + currentSlot);
   }
   function doLoad() {
       if(confirm("Load P" + currentSlot + "?")) {
           fetch("/load?p=" + currentSlot).then(r=>r.json()).then(d=>{
                 id('i_kp').value = d.kp; id('v_kp').innerText = d.kp;
                 id('i_ki').value = d.ki; id('v_ki').innerText = d.ki;
                 id('i_kd').value = d.kd; id('v_kd').innerText = d.kd;
                 id('i_sp').value = d.sp; id('v_sp').innerText = d.sp;
                 id('i_kps').value = d.kps; id('v_kps').innerText = d.kps;
                 id('i_kis').value = d.kis; id('v_kis').innerText = d.kis;
             });
       }
   }

   const LEN = 100;
   var dAng = new Array(LEN).fill(0);
   var dSpd = new Array(LEN).fill(0);
   var dBP = new Array(LEN).fill(0);
   var dBI = new Array(LEN).fill(0);
   var dBD = new Array(LEN).fill(0);

   function drawGraph(cid, datasets) {
      var c = id(cid); var ctx = c.getContext('2d');
      var w = c.width = c.clientWidth; var h = c.height = c.clientHeight;
      ctx.clearRect(0,0,w,h);
      ctx.strokeStyle = '#333'; ctx.beginPath(); ctx.moveTo(0, h/2); ctx.lineTo(w, h/2); ctx.stroke();

      datasets.forEach(ds => {
            if(id(ds.id).checked) {
                  ctx.strokeStyle = ds.color; ctx.lineWidth = ds.width || 1.5; ctx.beginPath();
                  for(var i=0; i<LEN; i++){
                        var val = ds.data[i];
                        var scale = ds.scale || 1.0;
                        var y = h/2 - (val * (h/2)/scale);
                        if(i==0) ctx.moveTo(0, y); else ctx.lineTo(i*(w/LEN), y);
                  }
                  ctx.stroke();
            }
      });
   }

   setInterval(function(){
      var startTime = Date.now();
      fetch("/data").then(r=>r.json()).then(d=>{
         var latency = Date.now() - startTime; 
         id("txtLat").innerText = latency + " ms";

         var mps = d.s * 0.000102; 
         
         // UPDATE ROBOT VISUALIZER (Angle + Speed)
         drawRobotVisualizer(d.a, d.s);
         
         // UPDATE LIVE TEXT
         id("txtAng").innerText = d.a.toFixed(2);
         id("txtSpd").innerText = mps.toFixed(2);

         dAng.push(d.a); dAng.shift();
         dSpd.push(d.s); dSpd.shift();
         dBP.push(d.bP); dBP.shift();
         dBI.push(d.bI); dBI.shift();
         dBD.push(d.bD); dBD.shift();

         drawGraph('cvsMaster', [
               {id:'cb_ang', data:dAng, color:'white',   scale:45, width:2},     
               {id:'cb_spd', data:dSpd, color:'cyan',    scale:12000},           
               {id:'cb_bp',  data:dBP,  color:'#ffcc00', scale:8000},            
               {id:'cb_bi',  data:dBI,  color:'#ff00ff', scale:8000},
               {id:'cb_bd',  data:dBD,  color:'#00ff00', scale:8000}
         ]);

      }).catch(e=>{
         id("txtLat").innerText = "OFF";
      });
   }, 100); 
</script>
</body>
</html>
)rawliteral";


// --- MAIN CONTROL LOOP ---
void MotorTaskCode( void * pvParameters ) {
   unsigned long lastTime = 0;
   
   for(;;) { 
      stepper1.runSpeed();
      stepper2.runSpeed();
      
      unsigned long now = millis();
      if (now - lastTime >= 10) { 
         
         if(sensorConnected) {
            sensors_event_t event; bno.getEvent(&event);
            displayAngle = event.orientation.z;
            if (displayAngle > 180) displayAngle -= 360;
         }

         if (abs(setPoint - displayAngle) > FALL_LIMIT) {
            speedOutput = 0; sumBalanceError = 0; sumSpeedError = 0;
            dbg_bP=0; dbg_bI=0; dbg_bD=0;
            stepper1.setSpeed(0); stepper2.setSpeed(0);
         } else {
            
            float term_sP = speedOutput * Kp_s;
            float term_sI = sumSpeedError * Ki_s;
            dbg_sP = term_sP; dbg_sI = term_sI;

            float driftCorrection = term_sP + term_sI;
            driftCorrection = constrain(driftCorrection, -MAX_TILT, MAX_TILT);
            
            desiredAngle = setPoint + driftCorrection + moveTilt; 

            sumSpeedError += speedOutput;
            sumSpeedError = constrain(sumSpeedError, -200000, 200000);

            // Balance PID
            float balanceError = desiredAngle - displayAngle;
            float rawOutput = 0;

            if (abs(balanceError) < deadband) {
               rawOutput = 0; sumBalanceError = 0;
               dbg_bP=0; dbg_bI=0; dbg_bD=0;
            } 
            else {
               sumBalanceError += balanceError;
               if ((balanceError > 0 && lastBalanceError < 0) || (balanceError < 0 && lastBalanceError > 0)) sumBalanceError = 0;
               sumBalanceError = constrain(sumBalanceError, -8000, 8000);

               float term_bP = Kp * balanceError; 
               float term_bI = Ki * sumBalanceError; 
               float term_bD = Kd * (balanceError - lastBalanceError);
               
               dbg_bP = term_bP; dbg_bI = term_bI; dbg_bD = term_bD;
               
               rawOutput = term_bP + term_bI + term_bD;
            }

            // Accel Limit
            float max_change = 300.0; 
            float change = rawOutput - speedOutput;
            if (change > max_change) change = max_change;
            if (change < -max_change) change = -max_change;
            speedOutput += change;

            lastBalanceError = balanceError;

            // Apply
            float s1 = speedOutput + turnSpeed;
            float s2 = -speedOutput + turnSpeed;
            s1 = constrain(s1, -MAX_HW_SPEED, MAX_HW_SPEED);
            s2 = constrain(s2, -MAX_HW_SPEED, MAX_HW_SPEED);
            stepper1.setSpeed(s1); stepper2.setSpeed(s2);
         }
         lastTime = now;
      }
   } 
}

// --- WEB HANDLERS ---
void handleRoot() {
   String s = index_html;
   s.replace("%KP%", String(Kp)); s.replace("%KI%", String(Ki)); s.replace("%KD%", String(Kd));
   s.replace("%SP%", String(setPoint)); s.replace("%KPS%", String(Kp_s, 5)); s.replace("%KIS%", String(Ki_s, 5));
   server.send(200, "text/html", s);
}

void handleSet() {
   if(server.hasArg("k") && server.hasArg("v")) {
      String key = server.arg("k"); float val = server.arg("v").toFloat();
      if(key=="bp") Kp=val; else if(key=="bi") Ki=val; else if(key=="bd") Kd=val;
      else if(key=="sp") setPoint=val; else if(key=="sp_p") Kp_s=val; else if(key=="sp_i") Ki_s=val;
   }
   server.send(200, "text/plain", "OK");
}

void handleSave() {
    if(server.hasArg("p")) {
        int p = server.arg("p").toInt();
        String s = "_" + String(p);
        preferences.putFloat(("kp" + s).c_str(), Kp); 
        preferences.putFloat(("ki" + s).c_str(), Ki); 
        preferences.putFloat(("kd" + s).c_str(), Kd);
        preferences.putFloat(("sp" + s).c_str(), setPoint);
        preferences.putFloat(("kps" + s).c_str(), Kp_s); 
        preferences.putFloat(("kis" + s).c_str(), Ki_s);
        server.send(200, "text/plain", "Saved");
    } else server.send(400, "text/plain", "Err");
}

void handleLoad() {
    if(server.hasArg("p")) {
        int p = server.arg("p").toInt();
        String s = "_" + String(p);
        
        Kp = preferences.getFloat(("kp" + s).c_str(), 420); 
        Ki = preferences.getFloat(("ki" + s).c_str(), 2.0); 
        Kd = preferences.getFloat(("kd" + s).c_str(), 200);
        setPoint = preferences.getFloat(("sp" + s).c_str(), 0);
        Kp_s = preferences.getFloat(("kps" + s).c_str(), 0.001); 
        Ki_s = preferences.getFloat(("kis" + s).c_str(), 0.0001);

        String json = "{";
        json += "\"kp\":" + String(Kp) + ",";
        json += "\"ki\":" + String(Ki) + ",";
        json += "\"kd\":" + String(Kd) + ",";
        json += "\"sp\":" + String(setPoint) + ",";
        json += "\"kps\":" + String(Kp_s, 5) + ",";
        json += "\"kis\":" + String(Ki_s, 5);
        json += "}";
        server.send(200, "application/json", json);
    } else server.send(400, "text/plain", "Err");
}

void handleMove() {
    if(server.hasArg("d")) {
        String d = server.arg("d");
        moveTilt = 0; turnSpeed = 0;
        if(d == "F") moveTilt = -1.5;   
        else if(d == "B") moveTilt = 1.5; 
        else if(d == "L") turnSpeed = -800; 
        else if(d == "R") turnSpeed = 800;  
    }
    server.send(200, "text/plain", "OK");
}

void handleData() {
   String json = "{";
   json += "\"a\":" + String(displayAngle) + ",";
   json += "\"s\":" + String(speedOutput) + ",";
   json += "\"bP\":" + String(dbg_bP) + ",";
   json += "\"bI\":" + String(dbg_bI) + ",";
   json += "\"bD\":" + String(dbg_bD) + ",";
   json += "\"sP\":" + String(dbg_sP) + ",";
   json += "\"sI\":" + String(dbg_sI);
   json += "}";
   server.send(200, "application/json", json);
}
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
void loop() {
   if (WiFi.status() == WL_CONNECTED) server.handleClient();
   delay(2);
}

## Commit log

2026-02-01 Rename project from 'Self-Balancing-Robot' to 'PCB V1'
2026-02-01 Add images to PCB V1 README
    Added images to the README for better visualization.
2026-02-01 Update images in README for PCB V1
2026-02-03 Update README with PCB version specifications
    Added detailed specifications and improvements for PCB versions 1 and 2, including power management and compatibility notes.
2026-02-03 Update important notes for PCB design V2
2026-02-13 Revise README for clarity and detail
    Updated project title and expanded README with detailed sections on project overview, assembly instructions, mathematical modeling, control strategy, and repository contents.
